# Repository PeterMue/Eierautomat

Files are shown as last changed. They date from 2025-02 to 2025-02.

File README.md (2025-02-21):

Eierautomat
===========

The Eierautomat project is an automated egg vending machine designed to provide a convenient and efficient way to dispense products (egg carton). This project leverages various hardware components and sensors to ensure accurate and reliable operation. The system is built using an Arduino microcontroller and integrates multiple features to enhance user experience and maintain operational integrity.

## Features

- **Automated Egg Dispensing**: The machine can dispense items automatically after payment.
- **Coin Acceptor Integration**: Accepts coins for payment and processes them accurately.
- **Balance Reset**: Automatically resets the account balance after a specified time, allowing the user to buy multiple items and use the change money for the next item purchase since the coin acceptor will not give change back.
- **Manual Dispense Switch**: Allows manual dispensing of items through a switch (admin).
- **Total and Resettable Counters**: Keeps track of the total number of items dispensed and provides a resettable counter for easy management.
- **Error Handling**: Includes error LEDs and mechanisms to handle and indicate errors.
- **Rotary Encoder**: Utilizes a rotary encoder for menu navigation and selection.
- **LCD Display**: Displays information and menus on an LCD screen for user interaction.
- **Progress Indicator**: Shows progress on the LCD screen during operations.
- **Factory Reset**: Provides an option to reset the machine to factory settings.

## Menu 

- **Long Press**: Open Menu / Go Back
- **Normal Press**: Enter edit mode or activate the selected item
- **Control Wheel**: Navigate up/down or increase/decrese a value when in edit mode

### Structure

- **Info**
  - **Sold**: Displays the number of sold items.
  - **Reset sold**: Resets the sold items counter.
  - **Total**: Displays the total number of items (since Factory Reset).
  - **GIT Version**: The build version

- **Settings**
  - **Price**
    - **Set Price**: Allows setting the price.
    - **Range**: 0 to 2500 ct.
  - **Balance Reset**
    - **Set Delay**: Allows setting the balance reset delay.
    - **Range**: 0 to 600 s.
  - **Speed**
    - **Set Speed**: Allows setting the dispenser speed.
    - **Range**: 0.0 to 1.0.
  - **Retries**
    - **Set Attempts**: Allows setting the maximum dispense attempts.
    - **Range**: 1 to 10.
  - **Wait**
    - **Set Time**: Allows setting the removal wait time.
    - **Range**: 1000 to 10000 ms.
  - **Block**
    - **Set Current**: Allows setting the motor block current.
    - **Range**: 0.0 to 2.0 A.
  - **Inrush**
    - **Set Time**: Allows setting the motor block inrush wait time.
    - **Range**: 0 to 250 ms.
  - **Coin Config**
    - **Interval**
      - **Set Delay**: Allows setting the coin pulse max delay.
      - **Range**: 10 to 500 ms.
    - **1 Pulse**
      - **Set Value**: Allows setting the value for 1 pulse.
      - **Range**: 0 to 200 ct.
    - **2 Pulse**
      - **Set Value**: Allows setting the value for 2 pulses.
      - **Range**: 0 to 200 ct.
    - **3 Pulse**
      - **Set Value**: Allows setting the value for 3 pulses.
      - **Range**: 0 to 200 ct.
    - **4 Pulse**
      - **Set Value**: Allows setting the value for 4 pulses.
      - **Range**: 0 to 200 ct.
    - **5 Pulse**
      - **Set Value**: Allows setting the value for 5 pulses.
      - **Range**: 0 to 200 ct.
    - **6 Pulse**
      - **Set Value**: Allows setting the value for 6 pulses.
      - **Range**: 0 to 200 ct.
  - **Factory Reset**
    - **Reset**: Resets the machine to factory settings.

- **Exit**: Exits the menu.

## Hardware Components

- **Arduino**: Arduino Mega2560
- **Motordriver**: Arduino Motorshield Rev3
- **Switch Breakout Board**: Manages various switches and sensors for the machine.
- **Display Breakout Board**: Connects the LCD display and other display-related components.
- **LCD**: 16x2 LCD Display via I2C
- **Rotary Encoder**: Facilitates user input and menu navigation.
- **Coin Acceptor**: Handles coin insertion and validation.
- **Relays**: Controls various electrical components within the machine.

## Wiring and Connections

### Switch Breakout Board

```
         DISPENSER_A

         +------- REMOVAL_LED (VCC/GND)
         |    +------- EMPTY_SWITCH
         |    |    +------- MIN_LIMIT_SWITCH
         |    |    |    +------- MAX_LIMIT_SWITCH
         |    |    |    |    +------- MAX_LIMIT_SWITCH2
         |    |    |    |    |
+--------------------------------+    A1 -> PIN 23
| ::   [_|_][_|_][_|_][_|_][_|_] |    A2 -> PIN 25
| ::    A-1  A-2  A-3  A-4  A-5  |    A3 -> PIN 27
| ::                             |    A4 -> PIN 29
| ::                             |    A5 -> PIN 31
| ::    Switch Breakout Board    |
| ::                             |    B1 -> PIN 41
| ::                             |    B2 -> PIN 39
| ::    B-1  B-2  B-3  B-4  B-5  |    B3 -> PIN 37
| ::   [_|_][_|_][_|_][_|_][_|_] |    B4 -> PIN 35
+--------------------------------+    B5 -> PIN 33
         |    |    |    |    |
         |    |    |    |    +------- MAX_LIMIT_SWITCH2
         |    |    |    +------- MAX_LIMIT_SWITCH
         |    |    +------- MIN_LIMIT_SWITCH
         |    +------- EMPTY_SWITCH
         +------- REMOVAL_LED (VCC/GND)

         DISPENSER_B
```

### Display Breakout Board

```
           +------- C-1: Screw Terminal to RJ-45
           | +----- H-1: Pin Header 
           | |                      
+-----+    | |               +---+  
| ::  |    | |               | _ |  
| ::  +----------------------+|_||
| ::  [ 1 .. 8 ]              |_|| --- C-4: Screw Terminal Common GND
| ::     ......(H-1)          |_|| 
| ::                           _ |
| ::            ...(H-2)      |_||
| ::  [1 .. 8] [1 .. 6]       |_|| --- C-5: Screw Terminal External Power (+12V)
| ::  +----------------------+|_||
| ::  |   |      | |         |   |
+-----+   |      | |         +---+    
          |      | |                      
          |      | +----- C-3: Screw Terminal
          |      +----- H-2: Pin Header 
          +------- C-2: Screw Terminal
```

 * Screw Terminals
    * C-1: Display Unit Connector 
        1. VCC -[internally wired]-> VCC
        2. GND -[internally wired]-> Common GND
        3. SDA -[internally wired]-> H-1:1
        4. SCL -[internally wired]-> H-1:2
        5. ENC-CLK -[internally wired]-> H-1:3
        6. ENC-DT -[internally wired]-> H-1:4
        7. (empty) -[internally wired]-> H-1:5
        8. ENC-SW -[internally wired]-> H-1:6
    * C-2: Common GND
        1. GND
        2. GND
        3. GND
        4. GND
        5. GND
        6. GND
    * C-3: Coin Acceptor and Relais
        1. VCC
        2. COIN_ACCEPTOR_PULSE -[internally wired]-> H-2:1
        3. ERROR_LED -[internally wired]-> ERROR_LED_PIN (43)
        4. COIN_ACCEPTOR_ENABLE -[internally wired]-> COIN_ACCEPTOR_ENABLE_PIN (45)
        5. DISPENSER_A_MANUAL_SWITCH -[internally wired]-> DISPENSER_A_MANUAL_SWITCH_PIN (47)
        6. DISPENSER_B_MANUAL_SWITCH -[internally wired]-> DISPENSER_B_MANUAL_SWITCH_PIN (49)
    * C-4: Common GND
    * C-5: External Power (+12V)
* Pin Header
    * H-1: Display Unit Connector Pin Header
        1. SDA -[external jumper wire]-> SDA (20)
        2. SCL -[external jumper wire]-> SCL (21)
        3. ENC-CLK -[external jumper wire]-> ROTARY_ENC_PIN_CLK (18)
        4. ENC-DT -[external jumper wire]-> ROTARY_ENC_PIN_DT (19)
        5. (empty)
        6. ENC-SW -[external jumper wire]-> ROTARY_ENC_PIN_SW (17)
    * H-2: Aux
        1. COIN_ACCEPTOR_PULSE -[external jumper wire]-> COIN_ACCEPTOR_PULSE_PIN (2)
        2. COIN_ACCEPTOR_ENABLE (unused)
        3. ERROR_LED (unused)

### Display Unit Connection (RJ-45)

*Wire colors from EIA/TIA-568A/B patch cable.*

| Pin | Wire Color | Signal |
|-----|---|---|
| 1 | Brown/White  | VCC |
| 2 | Brown | GND |
| 3 | Blue/White | SCL |
| 4 | Blue | SDA |
| 5 | Orange/White | ENC-CLK  |
| 6 | Orange | ENC-DT |
| 7 | Green/White  | empty |
| 8 | Green | ENC-SW |

# TODO

* [x] Reset account balance after n time.
* [x] Switch manual dispense
* [x] Reset
* [x] Total counter + resettable counter
* [ ] Shielded cable (CoinAcceptor)
* [x] VCC cable (relais card)
* [x] Detach interrupt when coin acceptor is disabled

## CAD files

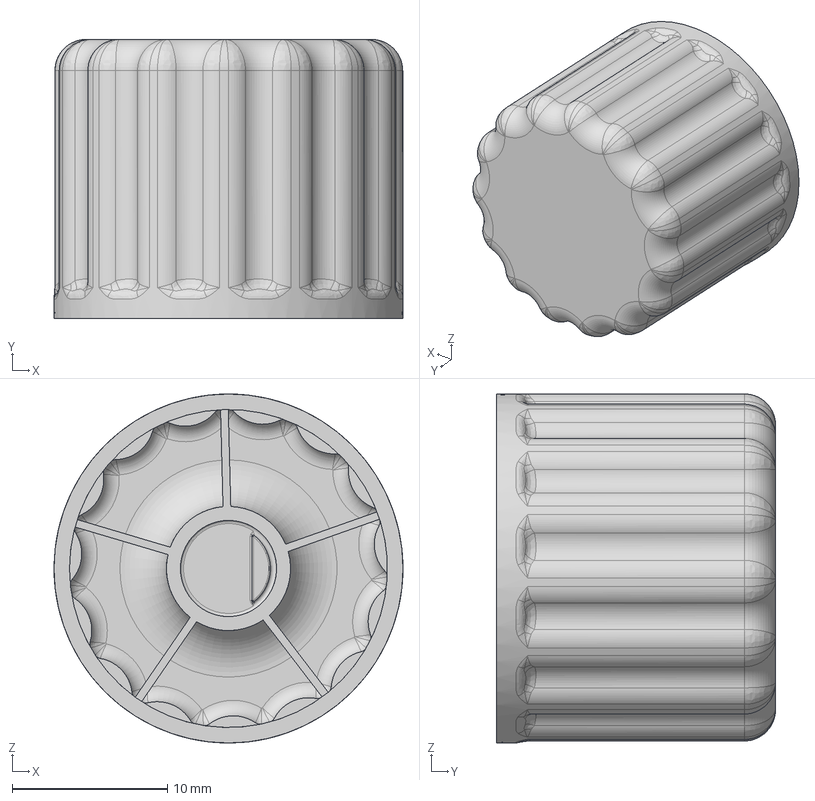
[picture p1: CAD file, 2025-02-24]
assets/lcd-knob.step
22.5 x 18.0 x 22.5 mm

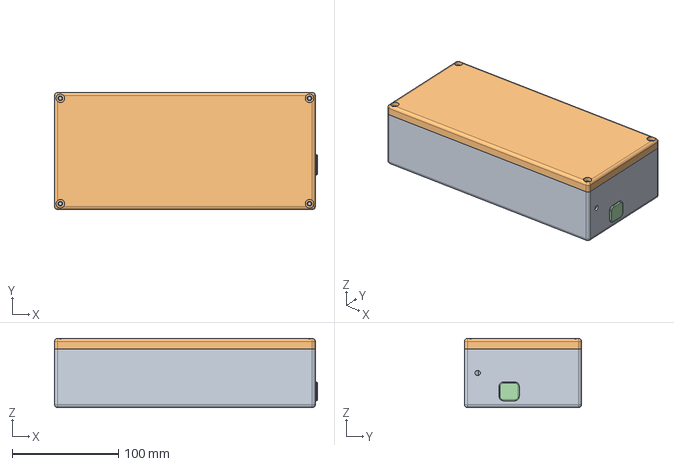
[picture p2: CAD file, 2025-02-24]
assets/controller-case.step.step
247.0 x 110.0 x 65.0 mm

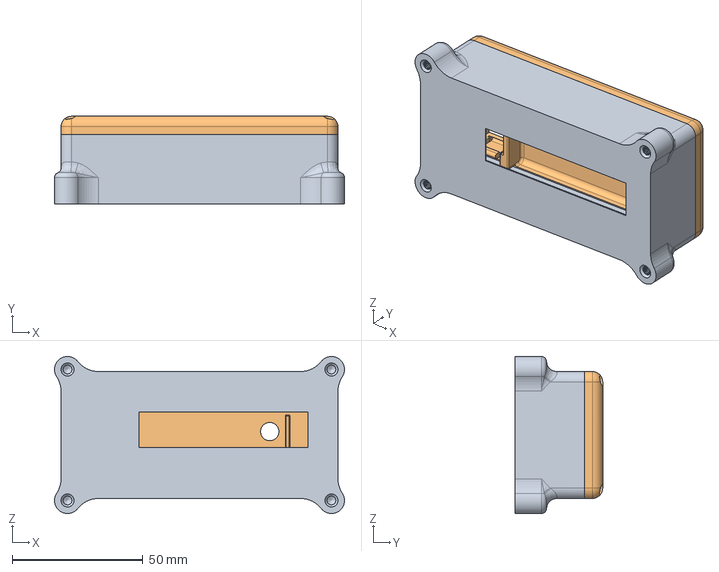
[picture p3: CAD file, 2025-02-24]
assets/lcd-case.step.step
111.0 x 33.5 x 60.1 mm

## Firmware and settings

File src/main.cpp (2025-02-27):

#include <Arduino.h>

#include "Display.h"
#include "coin/CoinAcceptor.h"
#include "config.h"
#include "debug.h"
#include "dispenser/Dispensers.h"
#include "motor/Motor.h"
#include "motor/Motorshield.h"

Storage *storage;
Dispensers *dispensers;
CoinAcceptor *coinAcceptor;
Display *display;
EasyLed *errorLed;

enum State { IDLE, AWAITING_PAYMENT, DISPENSING, EMPTY, OUT_OF_ORDER } state;

void setup() {
    Serial.begin(9600);

    # ifdef CLEAR_EEPROM
    Serial.println("Clearing EEPROM... (may take a while)");
    for (uint16_t i = 0 ; i < EEPROM.length() ; i++) {
        EEPROM.write(i, 0xFF);
    }
    #endif

    // initialization must happen here, otherwise something strange happens
    storage = Storage::instance;
    dispensers = Dispensers::instance;
    coinAcceptor = CoinAcceptor::instance;
    display = Display::instance;

    errorLed = new EasyLed(ERROR_LED_PIN, EasyLed::ActiveLevel::Low);

    display->begin();
    display->setText("Betriebsbereit");
    coinAcceptor->begin();
    dispensers->begin();
    state = IDLE;
    Debug::stateTransition("(none)", state, "Initialization complete");
}

Dispenser *activeDispenser = nullptr;

void loop() {
    display->loop();
    coinAcceptor->loop();
    dispensers->loop();

    unsigned int balance = coinAcceptor->getBalance();
    const unsigned int price = storage->price.get();

    switch (state) {
        case IDLE:
            coinAcceptor->enable();
            errorLed->off();
            display->setText("Betriebsbereit");
            if (!dispensers->ready()) {
                state = dispensers->empty() ? EMPTY : OUT_OF_ORDER;
                Debug::stateTransition("IDLE", state, "Dispenser not ready");
            } else if (balance > 0) {
                state = AWAITING_PAYMENT;
                Debug::stateTransition("IDLE", state, "Balance > 0 (" + String(balance / 100.0) + " EUR)");
            }
            break;
        case AWAITING_PAYMENT:
            coinAcceptor->enable();
            errorLed->off();
            display->setText("Guthaben: \n" + String(balance / 100.0) + " EUR");
            if (!dispensers->ready()) {
                state = OUT_OF_ORDER;
                Debug::stateTransition("AWAITING_PAYMENT", state, "Dispenser not ready");
            } else if (balance >= price) {
                if (coinAcceptor->withdraw(price)) {
                    activeDispenser = dispensers->dispense();
                    state = DISPENSING;
                    Debug::stateTransition("AWAITING_PAYMENT", state, "Withdraw successful");
                    Debug::log("Dispensing item on: " + String(nullptr == activeDispenser ? "<nullptr>" : activeDispenser->getInfo().id));
                }
            } else if(balance <= 0) {
                state = IDLE;
                Debug::stateTransition("AWAITING_PAYMENT", state, "Balance <= 0");
            }
            break;
        case DISPENSING:
            errorLed->off();
            coinAcceptor->disable();
            if (activeDispenser == nullptr) {
                state = OUT_OF_ORDER;
                Debug::stateTransition("DISPENSING", state, "activeDispenser == nullptr");
            } else {
                switch (activeDispenser->getState()) {
                    case Dispenser::IDLE:
                        state = IDLE;
                        Debug::stateTransition("DISPENSING", state, "Dispenser completed");
                        activeDispenser = nullptr;
                        dispensers->swap();
                        storage->sold.set(storage->sold.get() + 1);
                        storage->total.set(storage->total.get() + 1);
                        Debug::log("Sold items: " + String(storage->sold.get()) + " (" + String(storage->total.get()) + " total)");
                        break;
                    case Dispenser::DISPENSE:
                    case Dispenser::RECOVER:
                    case Dispenser::RETURN:
                        display->setText("Warenausgabe");
                        break;
                    case Dispenser::REMOVAL:
                        display->setText("Entnahme");
                        break;
                    case Dispenser::ERROR:
                        Debug::log("Error dispensing!");
                        if(dispensers->ready()) {
                            dispensers->swap();
                            activeDispenser = dispensers->dispense();
                            state = DISPENSING;
                            break;
                        }
                    default:
                        state = OUT_OF_ORDER;
                        Debug::stateTransition("DISPENSING", state, "Dispenser error");
                        break;
                }
                if(nullptr != activeDispenser && activeDispenser->getState() == Dispenser::REMOVAL) {
                    display->enableProgressIndicator();
                } else {
                    display->disableProgressIndicator();
                }
            }
            break;
        case EMPTY:
            errorLed->on();
            coinAcceptor->disable();
            display->setText("Leer");
            if (dispensers->ready()) {
                state = IDLE;
                Debug::stateTransition("EMPTY", state, "Dispenser ready");
            } else if (!dispensers->empty()) {
                state = OUT_OF_ORDER;
                Debug::stateTransition("EMPTY", state, "Dispenser not empty");
            }
            break;
        case OUT_OF_ORDER:
        default:
            errorLed->on();
            coinAcceptor->disable();
            display->setText("Ausser Betrieb\n+49 171 9422292");
            if (dispensers->ready()) {
                state = IDLE;
                Debug::stateTransition("OUT_OF_ORDER", state, "Dispenser ready");
            } else if (dispensers->empty()) {
                state = EMPTY;
                Debug::stateTransition("OUT_OF_ORDER", state, "Dispenser empty");
            }
            break;
    };
}

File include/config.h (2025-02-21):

#pragma once
#include <Arduino.h>

// Dispenser A
#define DISPENSER_A_REMOVAL_LED_PIN 23

#define DISPENSER_A_EMPTY_SWITCH_PIN 25
#define DISPENSER_A_EMPTY_SWITCH_MODE INPUT
#define DISPENSER_A_EMPTY_SWITCH_POLARITY LOW

#define DISPENSER_A_MIN_LIMIT_SWITCH_PIN 27
#define DISPENSER_A_MIN_LIMIT_SWITCH_MODE INPUT
#define DISPENSER_A_MIN_LIMIT_SWITCH_POLARITY LOW

#define DISPENSER_A_MAX_LIMIT_SWITCH_PIN 29
#define DISPENSER_A_MAX_LIMIT_SWITCH_MODE INPUT
#define DISPENSER_A_MAX_LIMIT_SWITCH_POLARITY LOW

#define DISPENSER_A_MAX_LIMIT_SWITCH2_PIN 31
#define DISPENSER_A_MAX_LIMIT_SWITCH2_MODE INPUT
#define DISPENSER_A_MAX_LIMIT_SWITCH2_POLARITY HIGH

#define DISPENSER_A_MANUAL_SWITCH_PIN 47
#define DISPENSER_A_MANUAL_SWITCH_MODE INPUT
#define DISPENSER_A_MANUAL_SWITCH_POLARITY HIGH

// Dispenser B
#define DISPENSER_B_REMOVAL_LED_PIN 41

#define DISPENSER_B_EMPTY_SWITCH_PIN 39
#define DISPENSER_B_EMPTY_SWITCH_MODE INPUT
#define DISPENSER_B_EMPTY_SWITCH_POLARITY LOW

#define DISPENSER_B_MIN_LIMIT_SWITCH_PIN 37
#define DISPENSER_B_MIN_LIMIT_SWITCH_MODE INPUT
#define DISPENSER_B_MIN_LIMIT_SWITCH_POLARITY LOW

#define DISPENSER_B_MAX_LIMIT_SWITCH_PIN 35
#define DISPENSER_B_MAX_LIMIT_SWITCH_MODE INPUT
#define DISPENSER_B_MAX_LIMIT_SWITCH_POLARITY LOW

#define DISPENSER_B_MAX_LIMIT_SWITCH2_PIN 33
#define DISPENSER_B_MAX_LIMIT_SWITCH2_MODE INPUT
#define DISPENSER_B_MAX_LIMIT_SWITCH2_POLARITY HIGH

#define DISPENSER_B_MANUAL_SWITCH_PIN 49
#define DISPENSER_B_MANUAL_SWITCH_MODE INPUT
#define DISPENSER_B_MANUAL_SWITCH_POLARITY HIGH

// Rotary encoder
#define ROTARY_ENC_PIN_CLK 18
#define ROTARY_ENC_PIN_DT 19
#define ROTARY_ENC_PIN_SW 17
#define ROTARY_ENC_DEBOUNCE_DELAY 10
#define ROTARY_ENC_ERROR_DELAY 250

// Settings
#define SETTINGS_MENU_LONG_PRESS_MS 2000

// Error led
#define ERROR_LED_PIN 43

// Display
#define LCD_I2C_ADDR 0x27
#define LCD_COLS 16
#define LCD_ROWS 2
#define DISPLAY_FPS 4

// Coin acceptor
#define COIN_ACCEPTOR_PULSE_PIN 2
#define COIN_ACCEPTOR_ENABLE_PIN 45
#define COIN_ACCEPTOR_INIT_DELAY 100

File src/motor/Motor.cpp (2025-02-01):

#include "Motorshield.h"

Motor::Motor(uint8_t dir, uint8_t pwm, uint8_t brake, uint8_t currentSense)
    : pin{dir, pwm, brake, currentSense},
      dir(CW),
      speed(0),
      currentSpeed(0),
      enabled(false),
      inrushWait(0),
      currentInrushWait(0),
      blockCurrent(0),
      sampleIndex(0),
      samplesRolled(false),
      lastSample(0),
      lastRamp(0) {
    pinMode(pin.dir, OUTPUT);
    pinMode(pin.pwm, OUTPUT);
    pinMode(pin.brake, OUTPUT);
    // pinMode(pin.current, INPUT); // necessary?
}

void Motor::enable(Direction dir, float speed) {
    if (this->enabled && this->dir != dir) {
        stop();
    }
    this->dir = dir;
    this->speed = std::clamp(MAX_SPEED_RAW * speed, MIN_SPEED_RAW, MAX_SPEED_RAW);
    this->enabled = true;
    this->inrushWait = 400;
}

void Motor::stop() {
    this->enabled = false;
    this->currentSpeed = 0;
    this->currentInrushWait = 0;
}

float Motor::amps() {
    float voltage = analogRead(pin.current) * (CURRENT_SENSE_MAX_VOLTAGE / 1023.0);
    return voltage / CURRENT_SENSE_AMPS_PER_VOLT;
}

float Motor::ampsAvg() {
    float sum = 0.0f;
    for (int i = 0; i < MAX_SAMPLES; i++) {
        sum += this->samples[i];
    }
    return sum / MAX_SAMPLES;
}

void Motor::configureBlockDetection(float blockCurrent, int inrushWait) {
    this->blockCurrent = blockCurrent;
    this->inrushWait = inrushWait;
}

bool Motor::blocked() {
    if (this->blockCurrent > 0) {
        return this->currentInrushWait >= this->inrushWait && this->amps() > this->blockCurrent;
    }
    return false;
}

void Motor::loop() {
    unsigned long now = millis();
    // speed ramping
    if (this->enabled) {
        if (now - this->lastRamp > 5) {
            this->lastRamp = now;
            if (this->currentSpeed < this->speed) {
                this->currentSpeed++;
            }
            if (this->currentInrushWait < this->inrushWait) {
                this->currentInrushWait++;
            }
        }
        analogWrite(pin.pwm, this->currentSpeed);
        digitalWrite(pin.dir, this->dir);
        digitalWrite(pin.brake, LOW);
    } else {
        analogWrite(pin.pwm, 0);
        digitalWrite(pin.brake, HIGH);
    }

    // amp sampling
    if (now - this->lastSample > 5) {
        this->lastSample = now;
        samples[sampleIndex] = amps();
        if (++sampleIndex >= MAX_SAMPLES) {
            samplesRolled = true;
            sampleIndex = 0;
        }
    }
}

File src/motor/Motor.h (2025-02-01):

#pragma once

#include <Arduino.h>

/**
 * Patch for missing std::clamp in Arduino
 */
namespace std {
template <typename T>
T clamp(T val, T min, T max) {
    if (val < min) return min;
    if (val > max) return max;
    return val;
}
}  // namespace std

class Motor {
   public:
    enum Direction { CW, CCW };

   public:
    Motor(uint8_t dir, uint8_t pwm, uint8_t brake, uint8_t currentSense);

    void enable(Direction dir, float speed);
    void stop();
    float amps();
    float ampsAvg();
    void loop();
    bool blocked();

    void configureBlockDetection(float blockCurent, int inrushWait);

   private:
    const struct Pin {
        uint8_t dir;
        uint8_t pwm;
        uint8_t brake;
        uint8_t current;
    } pin;

    static constexpr float MAX_SPEED_RAW = 255.0;
    static constexpr float MIN_SPEED_RAW = 0;
    static constexpr int MAX_SAMPLES = 10;
    static constexpr float CURRENT_SENSE_AMPS_PER_VOLT = 1.65;
    static constexpr float CURRENT_SENSE_MAX_VOLTAGE = 3.3;

    Direction dir;
    float speed;
    int currentSpeed;

    bool enabled;

    int inrushWait;
    int currentInrushWait;
    float blockCurrent;

    float samples[MAX_SAMPLES];
    int sampleIndex;
    bool samplesRolled;

    unsigned long lastSample;
    unsigned long lastRamp;
};

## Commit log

2025-02-01 feat: classes to work with Motorshield rev3
    * Motor: contorl dc motor on single channel
    * Motorshield: Motorshield rev3 with two channels
2025-02-01 refactor: Change Motorshield design
2025-02-01 build(deps): remove obsolete switch dependency
2025-02-02 fix: only refresh display when text changed
    [Display.cpp]
2025-02-02 fix: missing config entry
    [CoinAcceptor.cpp, config.h]
2025-02-21 feat: add progress indicator to display, move to i2c
2025-02-21 feat: add config options, fix storage bug
    * new menu: factory reset
    * info-screen: reset sold counter
    * info-screen: git commit id replaces version number
    * storage: offset eeprom start due to an issue in the first sector
    * storage: better defaults
    * feat: dynamically reset balance after a while
    [Dispenser.cpp, Display.cpp, Storage.cpp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]
2025-02-21 fix: improve coin acceptor isr handling
    [CoinAcceptor.cpp, config.h]
2025-02-24 feat: add CAD models
    [controller-case.step.step, lcd-case.step.step, lcd-knob.step]
2025-02-27 fix: individual timer for enable and balance reset
    Using a shared timer seems not to work as the cancel of a indiviual task cancels all
    [CoinAcceptor.cpp]
2025-02-27 fix: dispenser alternation
    * Swapping dispensers
    * Error recovery: dispense on second if first fails
    * State: revert to "IDLE" when balance is zero in "AWAITING_PAYMENT"
    [main.cpp]
